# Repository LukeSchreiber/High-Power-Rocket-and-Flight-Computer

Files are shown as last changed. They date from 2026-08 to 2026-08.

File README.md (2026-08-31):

# Model Rocket & ESP32 Flight Computer

A model rocket built from scratch around a custom ESP32-S3 flight computer that logs
barometric altitude, pressure, and temperature to onboard flash at 20 Hz.

The project covers the full build: airframe design in OpenRocket, custom fins, nose cone,
and launch-rail hardware modeled in SOLIDWORKS and 3D printed, firmware written in
Arduino/C++, a homemade igniter and safety-interlock launch controller, and flight testing.

**It flew, the log was recovered, and the measured apogee — 119.1 m (390.7 ft) — matched the
pre-flight OpenRocket prediction to within 0.2%.**

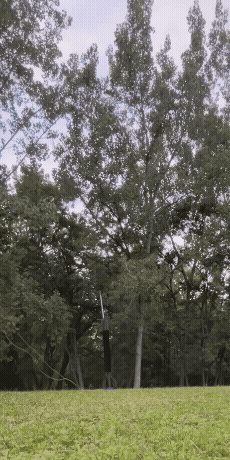
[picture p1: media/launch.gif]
Rocket launching from the field


---

## Flight Computer

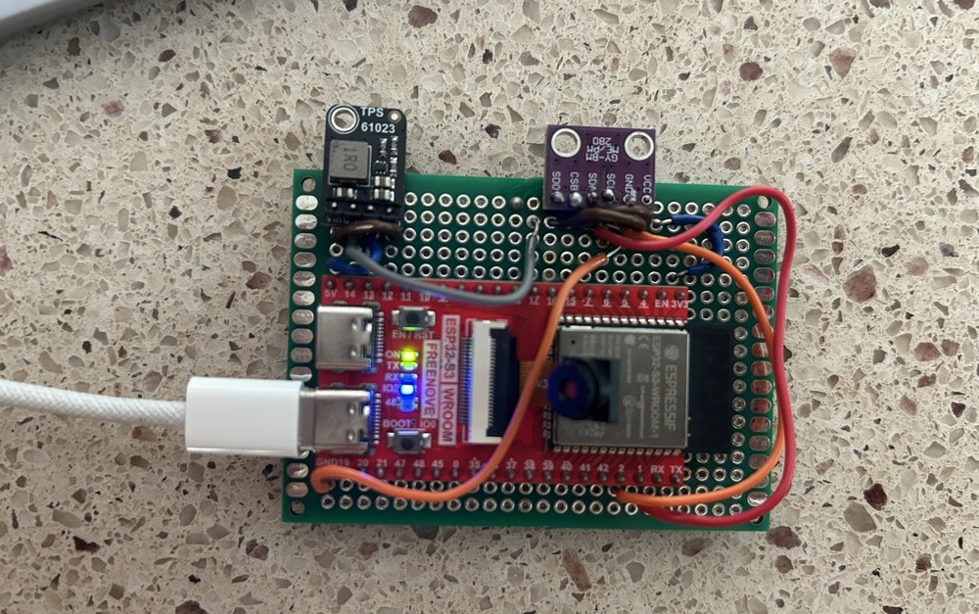
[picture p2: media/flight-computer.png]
ESP32-S3 flight computer on perfboard


| Part | Role |
| --- | --- |
| ESP32-S3 WROOM (Freenove) | Main controller, onboard LittleFS flash storage |
| BME280 (I²C, `0x76`) | Barometric pressure, temperature, derived altitude |
| TPS61023 boost converter | Steps battery voltage up to the board's power rail |
| Perfboard + soldered harness | Flight-ready wiring, no breadboard jumpers |

Wiring is I²C on `SDA = GPIO21`, `SCL = GPIO22`.

### Firmware

[`firmware/Flight_Computer_Program/Flight_Computer_Program.ino`](firmware/Flight_Computer_Program/Flight_Computer_Program.ino)

On boot the firmware averages 10 pressure samples to establish a ground baseline, opens the
next unused `flight_N.csv` on LittleFS, and logs continuously:

- **20 Hz sampling** (50 ms interval), pressure oversampled ×16 for resolution
- **Altitude** derived from the barometric formula against the ground baseline
- **Flushed to flash every second**, so an unexpected power loss costs at most 1 s of data
- **Auto-incrementing flight files** — a new log per power cycle, nothing overwritten

Logged columns: `time_ms, pressure_hPa, temperature_C, altitude_m`

### Serial commands

Connect at **115200 baud** and send a single character:

| Key | Action |
| --- | --- |
| `L` | List stored flight logs and flash usage |
| `D` | Dump all logs over serial for retrieval |
| `W` | Erase all logs |
| `S` | Pause / resume logging |

### Building

Requires the ESP32 board support package plus the `Adafruit_BME280` and `Adafruit_Sensor`
libraries. Open the sketch folder in the Arduino IDE, select an ESP32-S3 board, and upload.

---

## Mechanical Design

Custom components were modeled in SOLIDWORKS and 3D printed. Sources are in
[`cad/solidworks/`](cad/solidworks/), print-ready meshes in [`cad/stl/`](cad/stl/).

| Component | SOLIDWORKS | STL |
| --- | --- | --- |
| Fin can | [RocketFins.SLDPRT](cad/solidworks/RocketFins.SLDPRT) | [RocketFins.STL](cad/stl/RocketFins.STL) |
| Nose cone | [NoseCone.SLDPRT](cad/solidworks/NoseCone.SLDPRT) | [NoseCone.STL](cad/stl/NoseCone.STL) |
| Launch-rail clamp | [RocketClamp.SLDPRT](cad/solidworks/RocketClamp.SLDPRT) | [RocketClamp.STL](cad/stl/RocketClamp.STL) |

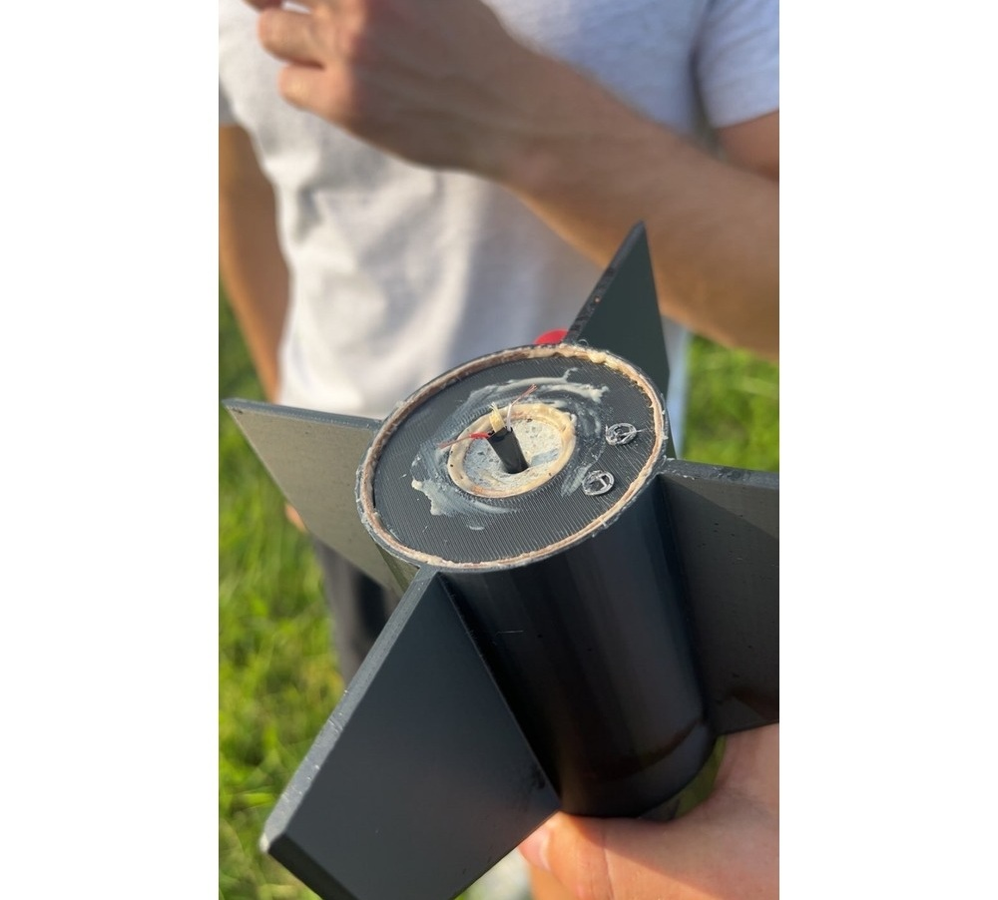
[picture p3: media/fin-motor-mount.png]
Printed fin can and motor mount


The finished airframe — 3D-printed fin can, nose cone, and painted body tube:

<table>
  <tr>
    <td align="center">
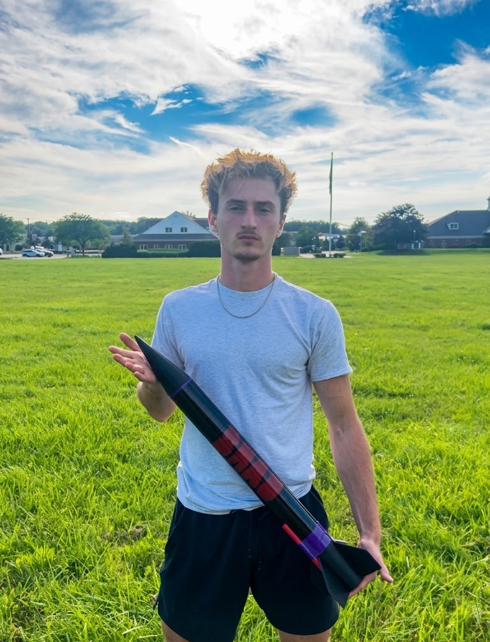
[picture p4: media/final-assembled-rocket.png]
Adriano holding the completed rocket
      <br>
      <sub>Adriano with the completed rocket</sub>
    </td>
    <td align="center">
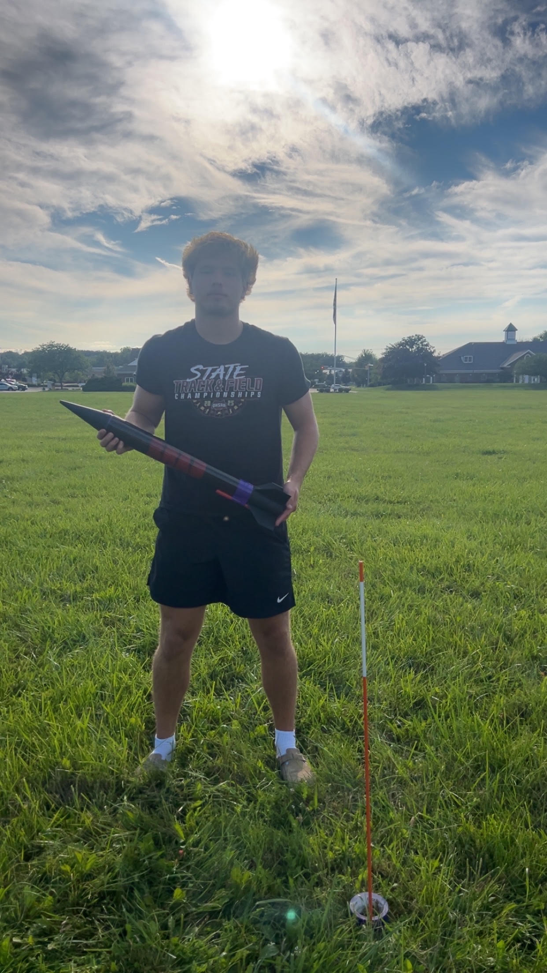
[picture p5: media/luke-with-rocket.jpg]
Luke holding the rocket beside the launch rod
      <br>
      <sub>Luke at the pad before launch</sub>
    </td>
  </tr>
</table>

Recovery is a parachute deployed by the motor's ejection charge.

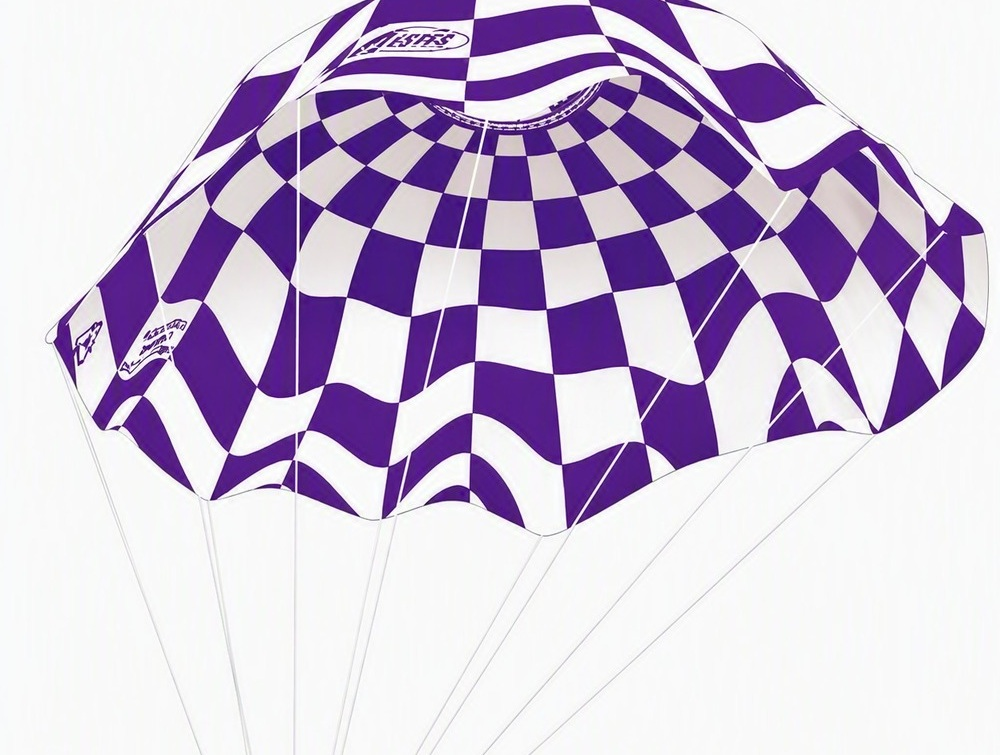
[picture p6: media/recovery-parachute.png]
Recovery parachute


---

## Simulation

[`simulation/RocketProject.ork`](simulation/RocketProject.ork) — OpenRocket model used to size
the airframe and predict the flight profile.

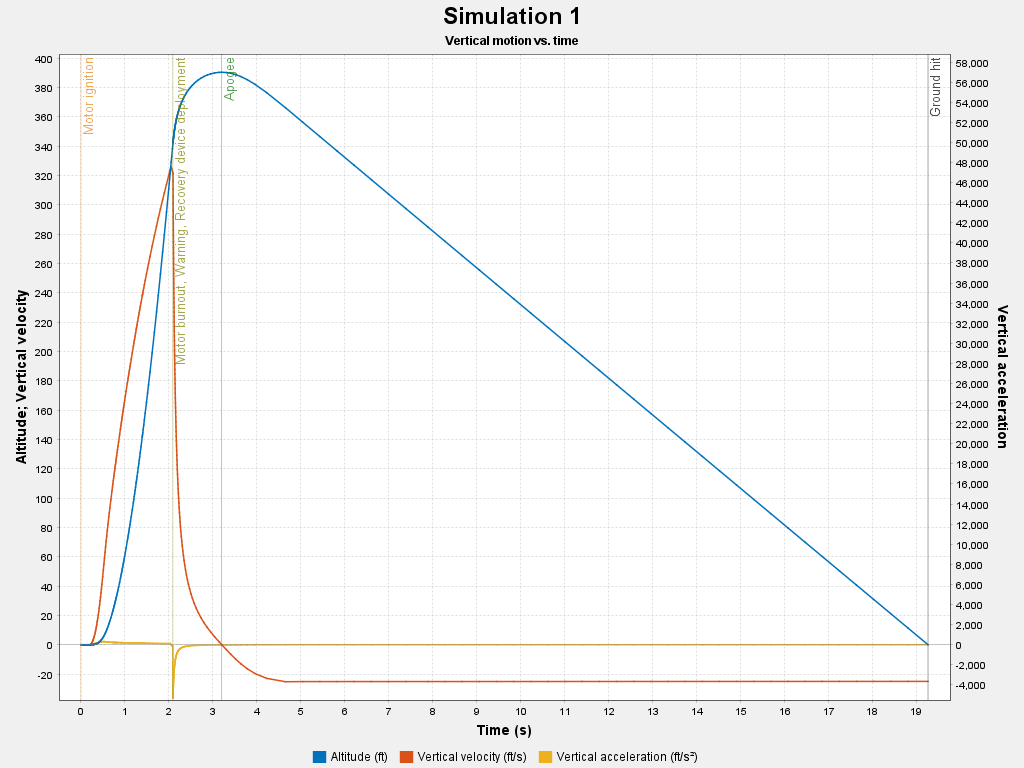
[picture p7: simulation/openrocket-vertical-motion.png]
OpenRocket vertical motion vs. time


| Predicted | Value |
| --- | --- |
| Apogee | 390 ft |
| Time to apogee | 3.2 s |
| Total flight time | 19.3 s |
| Peak velocity | 327 ft/s |
| Peak acceleration | 317 ft/s² |

[`simulation/synthetic_flight_log.xlsx`](simulation/synthetic_flight_log.xlsx) is a phase-labeled
dataset generated from this simulation — not measured telemetry, and marked
`Data_Source = SYNTHETIC_SIMULATION` in the file itself. The real flight log is
[`data/flight_data.csv`](data/flight_data.csv) below.

---

## Measured Flight Data

[`data/flight_data.csv`](data/flight_data.csv) — **401 samples recovered from the flight
computer's flash after the launch.** Twenty seconds of pressure, temperature, and derived
altitude at a steady 20 Hz, exactly as the firmware wrote them.

<picture>
  <source media="(prefers-color-scheme: dark)" srcset="data/flight-profile-dark.svg">
  Measured altitude vs. time: launch, apogee at 119.1 m after 3.2 s, parachute descent, touchdown at 19.2 s
</picture>

| Measurement | Value |
| --- | --- |
| Apogee | **119.1 m (390.7 ft)** at t = 3.20 s |
| Peak climb rate | 94 m/s (307 ft/s) at t ≈ 2.0 s |
| Descent rate under parachute | 7.6 m/s (24.8 ft/s) |
| Touchdown | t = 19.2 s |
| Pressure swing | 1008.79 → 994.57 hPa |
| Temperature | 24.80 °C on the pad → 24.32 °C at apogee |
| Sensor noise on the ground | ±0.2 m |

### Measured vs. predicted

The OpenRocket model was built before the flight. Comparing it against what the rocket
actually did is the real result here:

| | Predicted | Measured | Difference |
| --- | --- | --- | --- |
| Apogee | 390 ft | 390.7 ft | +0.2% |
| Time to apogee | 3.2 s | 3.20 s | — |
| Total flight time | 19.3 s | 19.2 s | −0.5% |
| Peak velocity | 327 ft/s | 307 ft/s | −6% |

Apogee and timing matched the simulation to within a fraction of a percent. The velocity gap
is expected: the flight computer carries no accelerometer, so climb rate is finite-differenced
from barometric altitude, which lags during the ~2 s burn and smooths the true peak.

The ±0.2 m spread in the pre-launch and post-landing samples is the practical altitude
resolution of the BME280 at this configuration — small enough that a 119 m apogee is resolved
to better than 0.2%.

---

## Launch System

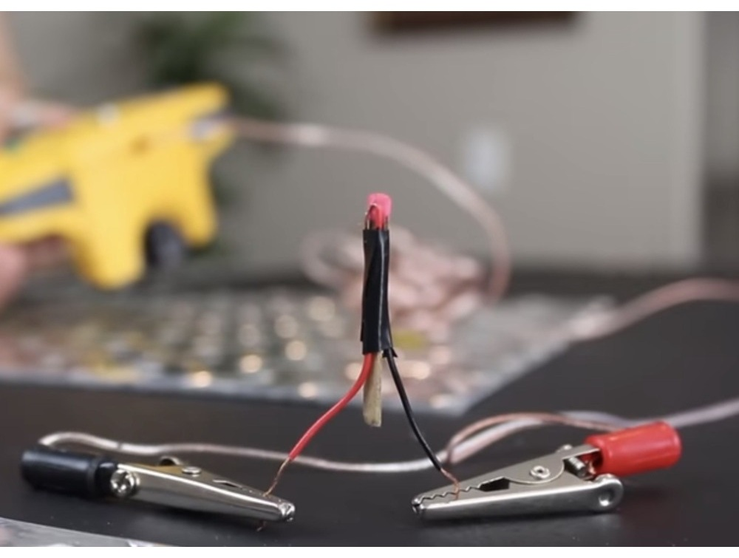
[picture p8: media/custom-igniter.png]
Hand-built nichrome igniter

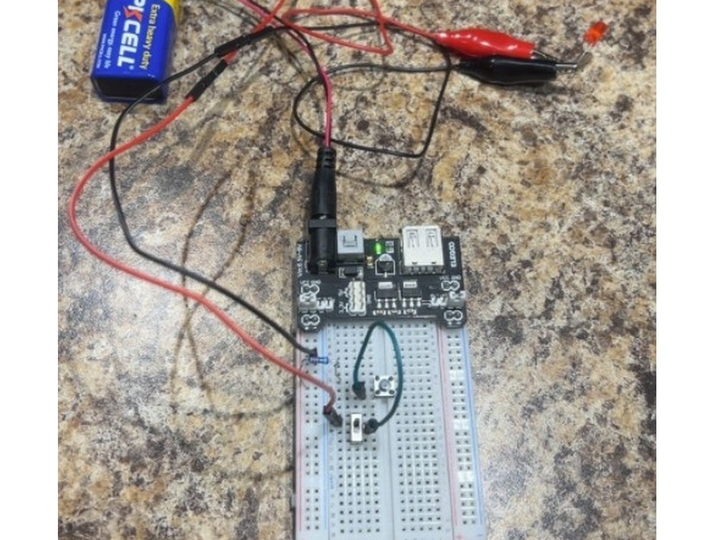
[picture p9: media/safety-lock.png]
Launch controller with safety interlock


A hand-built nichrome igniter fired from a 9 V controller with a **two-stage safety
interlock** — an arming switch in series with a momentary launch button, so the igniter
cannot be energized by a single accidental press.

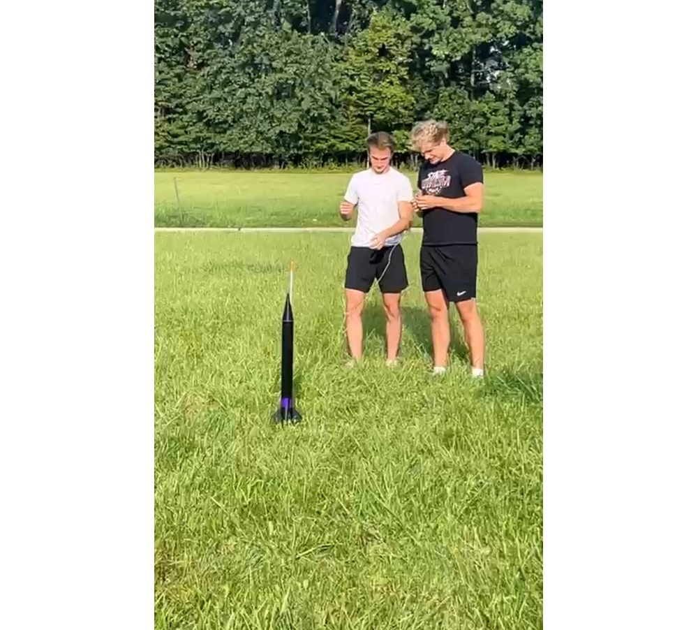
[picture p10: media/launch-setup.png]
Rocket on the pad before launch


---

## Documentation

- [Project report](docs/rocket-flight-computer-report.pdf) — written write-up of the design and build
- [Photo report](docs/rocket-flight-computer-photo-report.pdf) — illustrated build documentation

---

## Repository Structure

```text
.
├── firmware/
│   └── Flight_Computer_Program/     Arduino sketch (ESP32-S3 + BME280 logger)
├── cad/
│   ├── solidworks/                  Editable SOLIDWORKS parts
│   └── stl/                         Print-ready meshes
├── simulation/                      OpenRocket model, predicted profile, synthetic dataset
├── data/                            Measured flight log (CSV) + rendered profile
├── docs/                            Project reports (PDF)
└── media/                           Launch footage and build photos
```

---

## Skills

Embedded C++ · ESP32 · I²C sensor integration · onboard data logging · flight-data analysis ·
simulation validation · SOLIDWORKS · 3D printing · OpenRocket · circuit prototyping and
soldering · flight testing

---

## Status

**Complete and flight-validated.** The airframe, avionics, and launch system were built,
flown, and recovered, and the onboard log was pulled from flash after the flight — the
measured apogee matched the pre-flight simulation to within 0.2%.

---

## Authors

Built as a two-person team project by **Adriano Zagar** and **Luke Schreiber**.

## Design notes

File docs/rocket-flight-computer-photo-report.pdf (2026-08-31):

# Rocket & Flight Computer

LUKE SCHREIBER & TEAM | EMBEDDED C++ / ESP32-S3 / SOLIDWORKS / OPENROCKET

FLIGHT COMPUTER ESP32-S3, hand-soldered perfboard, SD logging

SENSING | BME280 barometric altitude
POWER | TPS61023 boost converter
STRUCTURES | 3D-printed fins, nose cone, motor mount
RECOVERY | Parachute, validated canopy geometry
IGNITION | Custom igniter, key-locked interlock

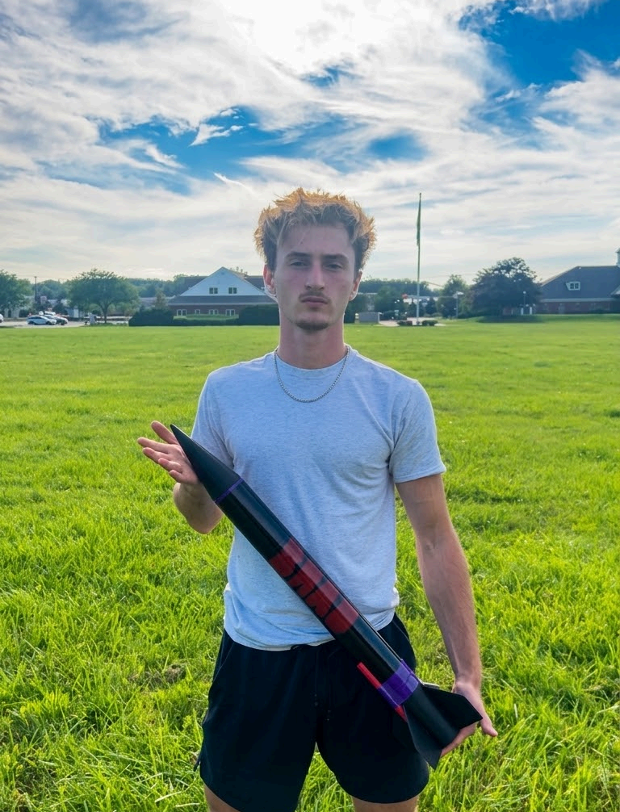
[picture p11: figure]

Final assembled rocket

B U I L D P R O C E S S

01
DESIGN
SOLIDWORKS

02
SIMULATE
OpenRocket

03
FABRICATE
3D print & assemble

04
AVIONICS
Solder & code

05
INTEGRATE
Bench test

06
FLY
Field launches

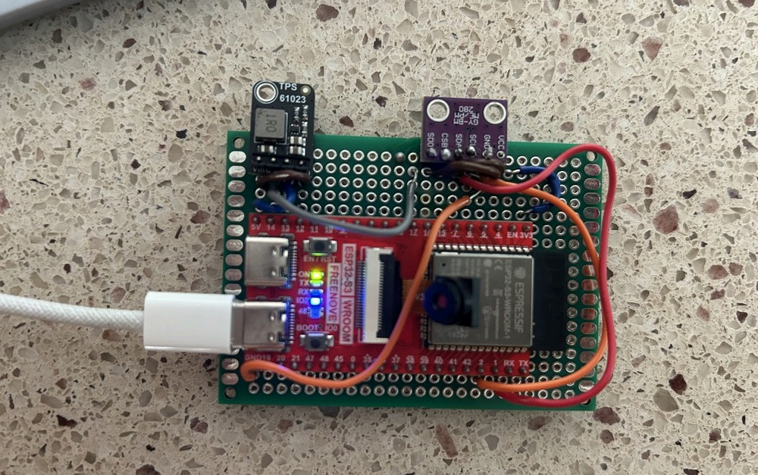
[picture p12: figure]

Flight Computer
ESP32-S3 + BME280

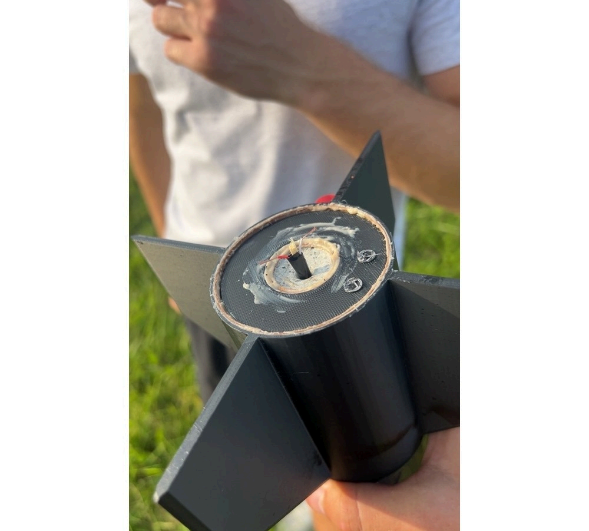
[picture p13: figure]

Fin & Motor Mount
3D printed

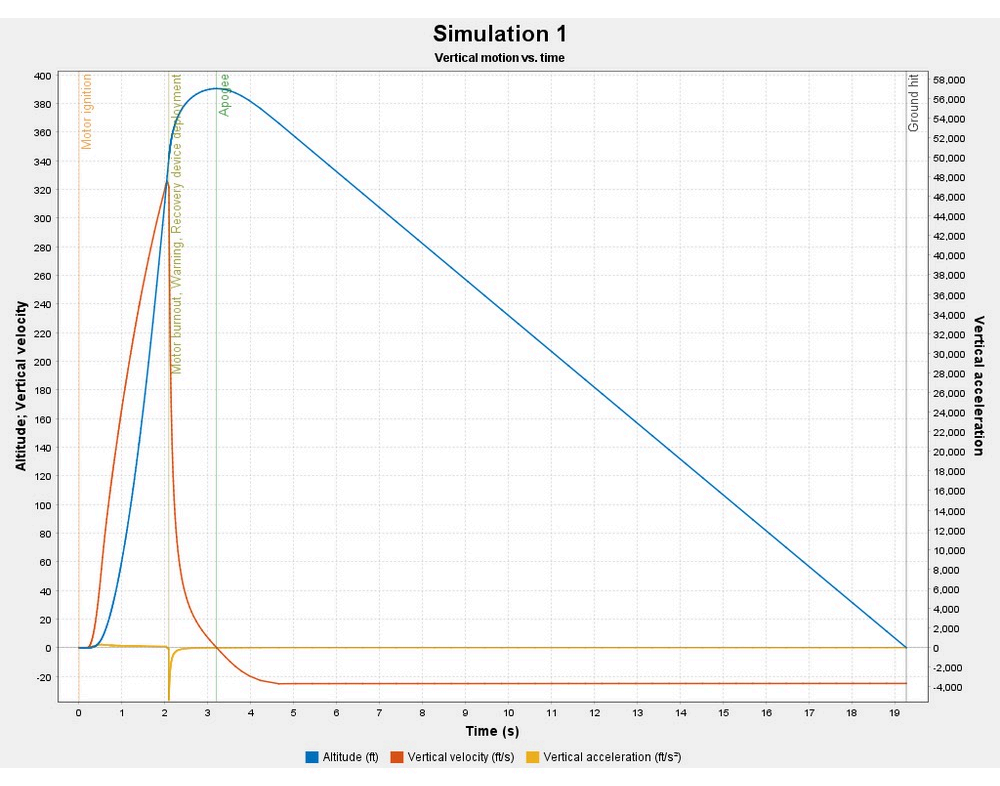
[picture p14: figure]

Flight Simulation
OpenRocket

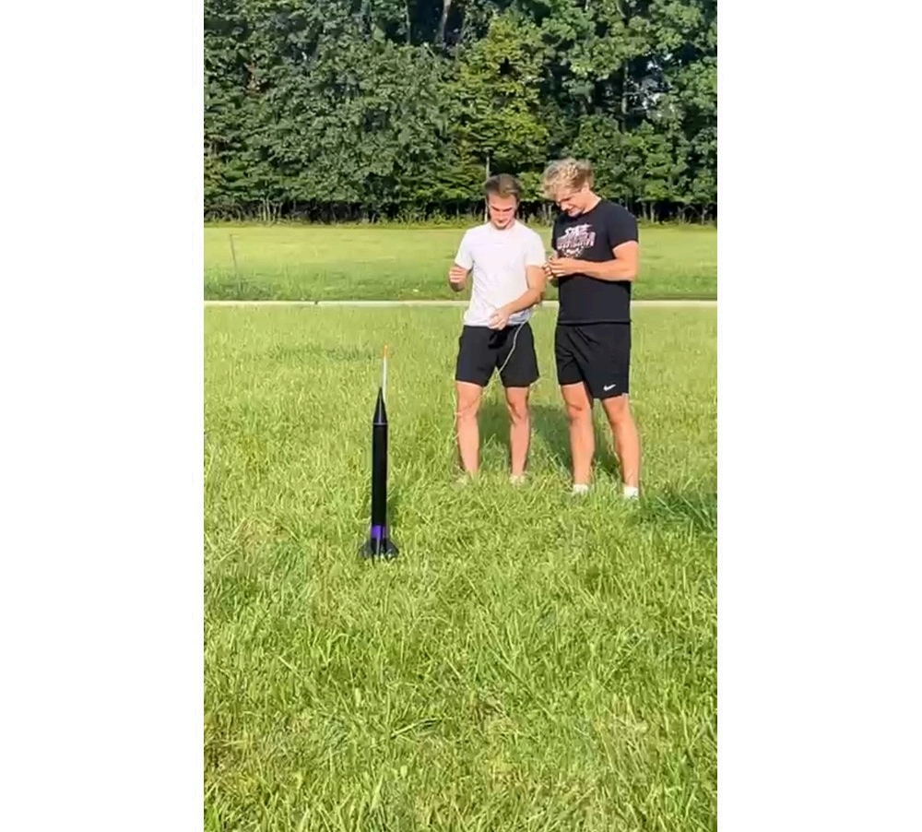
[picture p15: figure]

Launch Setup
Field test

E N G I N E E R I N G H I G H L I G H T S

Igniter built from scratch
No off-the-shelf igniter

Key-locked interlock
Blocks accidental ignition

Validated recovery
Canopy sized for safe descent

Full integration
One flight-ready stack

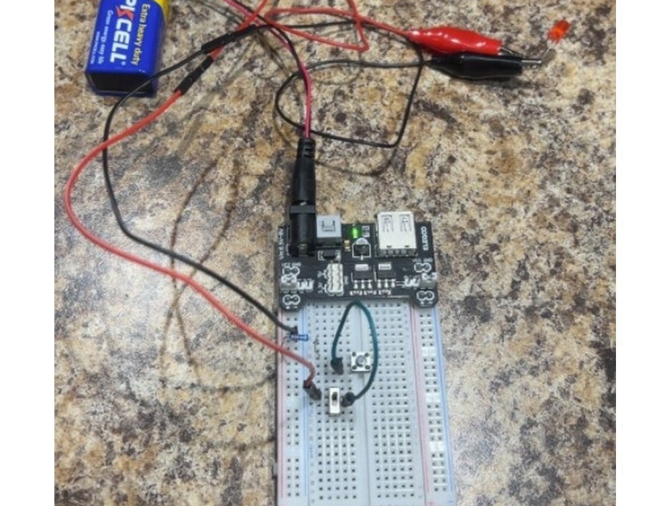
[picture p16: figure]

Safety Lock
Keyed interlock prototype

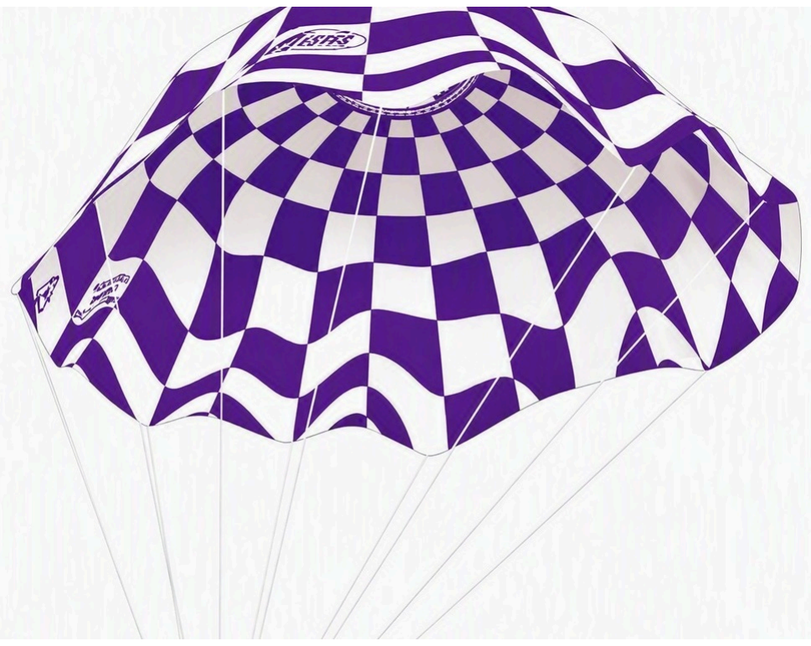
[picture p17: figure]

Recovery Parachute
Canopy layout

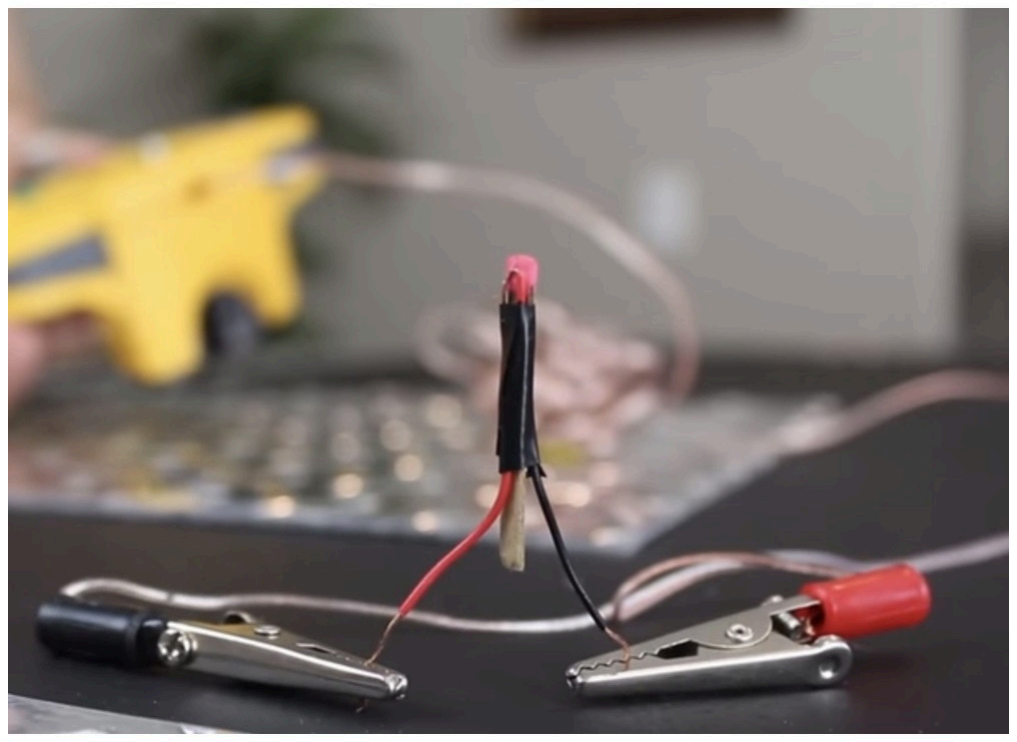
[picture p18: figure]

Custom Igniter
Bench test
LUKE SCHREIBER & TEAM | EMBEDDED SYSTEMS / AEROSTRUCTURES / SYSTEMS INTEGRATION

High-power rocket built with custom avionics, 3D-printed aerostructures, parachute recovery, key-locked ignition.

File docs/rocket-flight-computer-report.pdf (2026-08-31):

# TEAM-DEVELOPED ROCKET AND FLIGHT COMPUTER

Adriano Zagar & Team
Tech Stack: Embedded C++, ESP32-S3, SOLIDWORKS, OpenRocket

OBJECTIVE:Engineered and launched a custom high-power rocket with a self-built ESP32-S3 flight computer, 3D-printed aerostructures, and a custom ignition and safety-lock system.

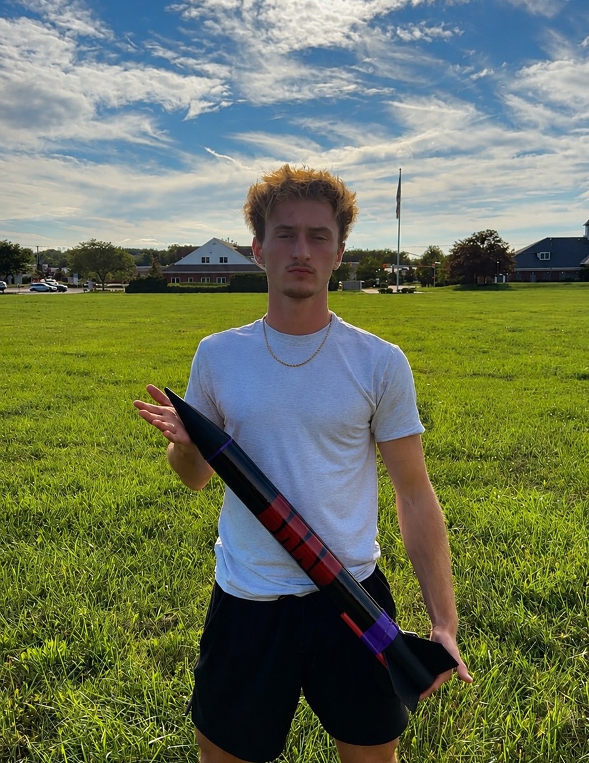
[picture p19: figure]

Final Assembled Rocket

## DEVELOPMENT WORKFLOW

- 1. Flight Computer: Engineered and coded a custom ESP32-S3 flight computer with real-time SD data logging.
- 2. Aerodynamics: Modeled and validated flight stability using OpenRocket simulations.
- 3. Sensor Integration: Integrated a BME280 pressure sensor and TPS61023 boost converter for altitude tracking and stable power delivery.
- 4. 3D-Printed Parts: Designed and fabricated custom fins and nose cone in SOLIDWORKS.
- 5. Ignition & Recovery: Engineered a custom ignition circuit and parachute recovery system from the ground up.
- 6. Flight Testing: Ran iterative test launches to validate flight computer and recovery performance.

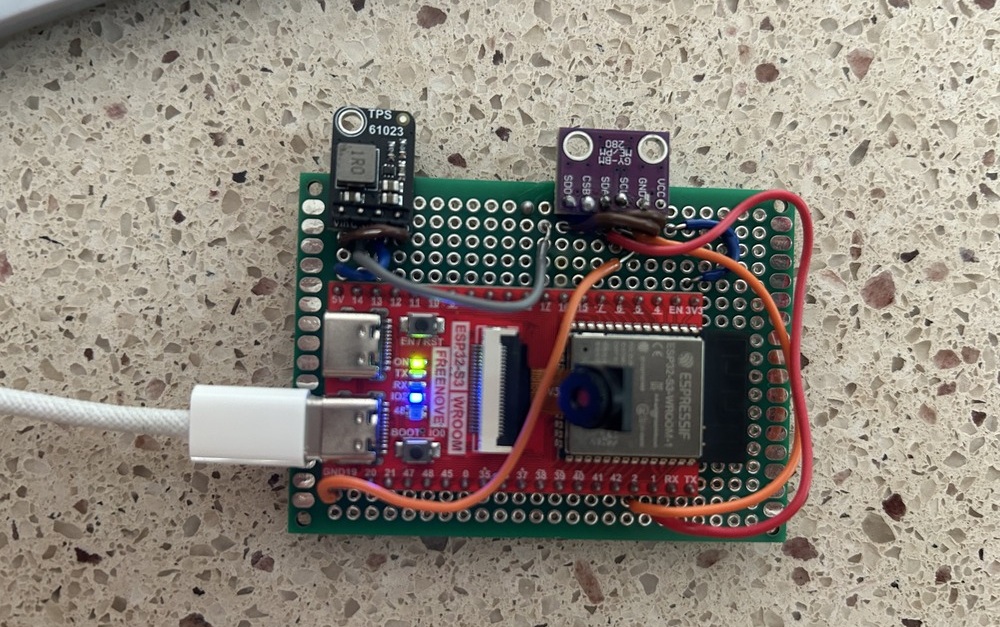
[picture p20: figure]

ESP32-S3 Flight
Computer

3D-Printed Fin & Motor
Mount
OpenRocket Flight Simulation | Rocket Setup

## ENGINEERING CHALLENGES & SOLUTIONS

- Custom Ignition System: Built and tested our own motor igniter circuit rather than using a pre-made one.
- Launch Safety Interlock: Engineered a key-locked launch interlock, adding a dedicated safety stage to prevent accidental ignition.
- Recovery System: Designed and validated parachute deployment and canopy geometry for a safe, controlled descent.
- Full Integration: Unified custom firmware, sensors, and recovery hardware into one fully integrated, flight-ready system.

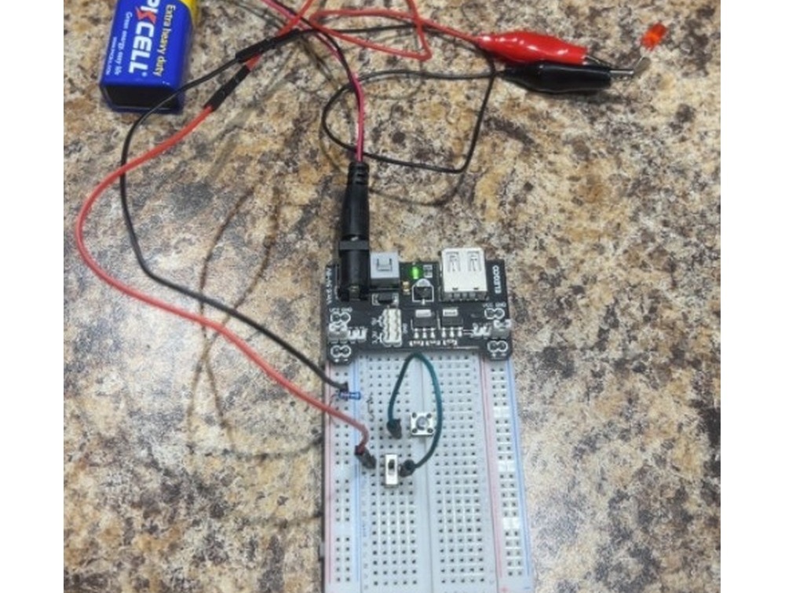
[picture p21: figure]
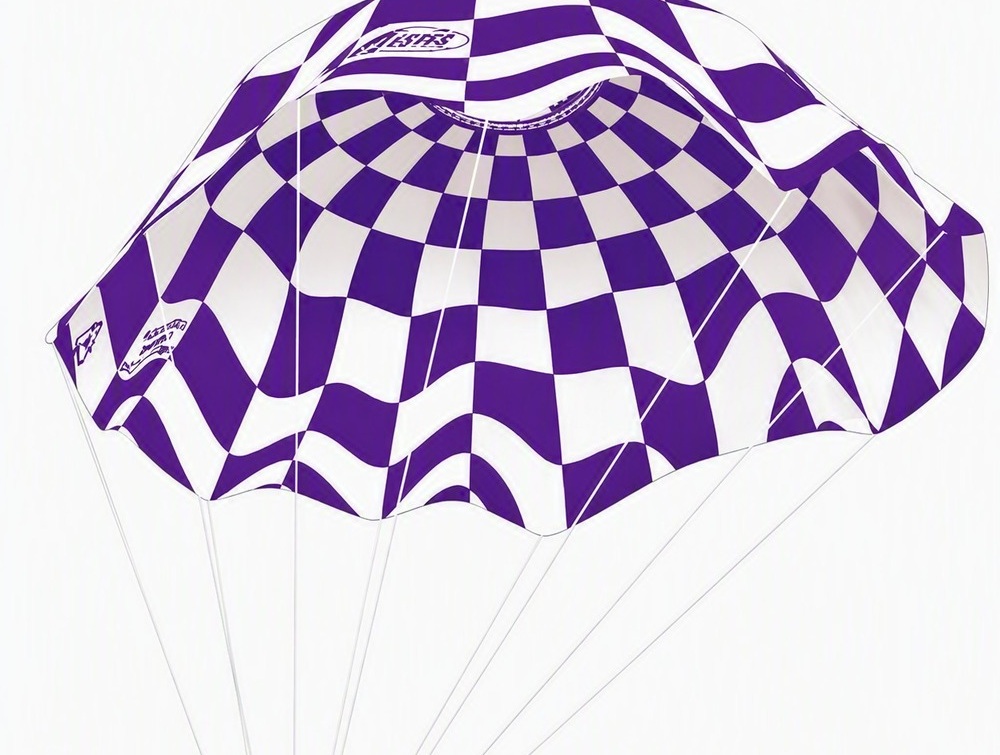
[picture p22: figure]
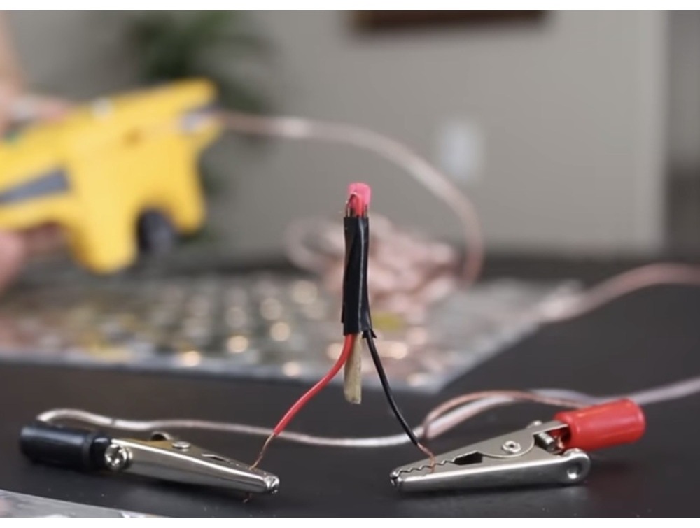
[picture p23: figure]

Safety Lock Prototype | Recovery Parachute | Custom-Built Igniter

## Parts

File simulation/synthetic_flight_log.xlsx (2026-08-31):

Synthetic Rocket Flight Log
Generated from the OpenRocket reference simulation. This is synthetic demonstration data, not an actual launch record.
Target Apogee | Time to Apogee | Total Flight Time | Peak Velocity | Peak Acceleration | Source
390 ft | 3.2 s | 19.3 s | 327 ft/s | 317 ft/s^2 | Synthetic simulation
Time_s | Altitude_ft | Pressure_hPa | Temperature_C | Vertical_Velocity_ft_s | Vertical_Acceleration_ft_s2 | Flight_Phase | Data_Source
0.0 | 0.18 | 1013.24 | 22.40 | 0.00 | 86.00 | Ignition | SYNTHETIC_SIMULATION
0.1 | 0.90 | 1013.28 | 22.41 | 8.63 | 86.72 | Ignition | SYNTHETIC_SIMULATION
0.2 | 2.32 | 1013.27 | 22.43 | 17.38 | 88.58 | Powered Ascent | SYNTHETIC_SIMULATION
0.3 | 4.39 | 1013.21 | 22.43 | 26.38 | 91.58 | Powered Ascent | SYNTHETIC_SIMULATION
0.4 | 7.17 | 1013.09 | 22.44 | 35.74 | 95.72 | Powered Ascent | SYNTHETIC_SIMULATION
0.5 | 10.86 | 1012.92 | 22.44 | 45.56 | 101.00 | Powered Ascent | SYNTHETIC_SIMULATION
0.6 | 15.67 | 1012.69 | 22.44 | 55.97 | 107.42 | Powered Ascent | SYNTHETIC_SIMULATION
0.7 | 21.78 | 1012.40 | 22.43 | 67.08 | 114.98 | Powered Ascent | SYNTHETIC_SIMULATION
0.8 | 29.26 | 1012.08 | 22.42 | 79.01 | 123.68 | Powered Ascent | SYNTHETIC_SIMULATION
0.9 | 38.09 | 1011.74 | 22.40 | 91.86 | 133.52 | Powered Ascent | SYNTHETIC_SIMULATION
1.0 | 48.20 | 1011.38 | 22.38 | 105.75 | 144.50 | Powered Ascent | SYNTHETIC_SIMULATION
1.1 | 59.59 | 1011.00 | 22.35 | 120.80 | 156.62 | Powered Ascent | SYNTHETIC_SIMULATION
1.2 | 72.33 | 1010.59 | 22.32 | 137.11 | 169.88 | Powered Ascent | SYNTHETIC_SIMULATION
1.3 | 86.64 | 1010.12 | 22.28 | 154.81 | 184.28 | Powered Ascent | SYNTHETIC_SIMULATION
1.4 | 102.83 | 1009.58 | 22.23 | 174.01 | 199.82 | Powered Ascent | SYNTHETIC_SIMULATION
1.5 | 121.18 | 1008.94 | 22.18 | 194.81 | 216.50 | Powered Ascent | SYNTHETIC_SIMULATION
1.6 | 141.93 | 1008.18 | 22.13 | 217.34 | 234.32 | Powered Ascent | SYNTHETIC_SIMULATION
1.7 | 165.20 | 1007.30 | 22.07 | 241.71 | 253.28 | Powered Ascent | SYNTHETIC_SIMULATION
1.8 | 191.02 | 1006.31 | 22.00 | 268.04 | 273.38 | Powered Ascent | SYNTHETIC_SIMULATION
1.9 | 219.45 | 1005.21 | 21.93 | 296.43 | 294.62 | Powered Ascent | SYNTHETIC_SIMULATION
2.0 | 250.58 | 1004.03 | 21.85 | 327.00 | 317.00 | Powered Ascent | SYNTHETIC_SIMULATION
2.1 | 280.57 | 1002.90 | 21.78 | 278.28 | -467.64 | Coast to Apogee | SYNTHETIC_SIMULATION
2.2 | 305.79 | 1001.99 | 21.73 | 233.47 | -428.61 | Coast to Apogee | SYNTHETIC_SIMULATION
2.3 | 326.78 | 1001.25 | 21.68 | 192.56 | -389.58 | Coast to Apogee | SYNTHETIC_SIMULATION
2.4 | 344.07 | 1000.68 | 21.64 | 155.56 | -350.56 | Coast to Apogee | SYNTHETIC_SIMULATION
2.5 | 358.06 | 1000.23 | 21.61 | 122.45 | -311.53 | Coast to Apogee | SYNTHETIC_SIMULATION
2.6 | 369.07 | 999.89 | 21.59 | 93.25 | -272.50 | Coast to Apogee | SYNTHETIC_SIMULATION
2.7 | 377.33 | 999.62 | 21.58 | 67.95 | -233.47 | Coast to Apogee | SYNTHETIC_SIMULATION
2.8 | 383.09 | 999.42 | 21.58 | 46.56 | -194.44 | Coast to Apogee | SYNTHETIC_SIMULATION
2.9 | 386.68 | 999.27 | 21.58 | 29.06 | -155.42 | Coast to Apogee | SYNTHETIC_SIMULATION
3.0 | 388.58 | 999.15 | 21.59 | 15.47 | -116.39 | Coast to Apogee | SYNTHETIC_SIMULATION
3.1 | 389.30 | 999.07 | 21.60 | 5.78 | -77.36 | Coast to Apogee | SYNTHETIC_SIMULATION
3.2 | 389.40 | 999.01 | 21.61 | 0.00 | -38.33 | Apogee | SYNTHETIC_SIMULATION
3.3 | 387.06 | 999.05 | 21.63 | -24.22 | 0.00 | Parachute Descent | SYNTHETIC_SIMULATION
3.4 | 384.94 | 999.12 | 21.65 | -24.22 | 0.00 | Parachute Descent | SYNTHETIC_SIMULATION
3.5 | 382.89 | 999.21 | 21.67 | -24.22 | 0.00 | Parachute Descent | SYNTHETIC_SIMULATION
3.6 | 380.75 | 999.33 | 21.69 | -24.22 | 0.00 | Parachute Descent | SYNTHETIC_SIMULATION
3.7 | 378.40 | 999.48 | 21.70 | -24.22 | 0.00 | Parachute Descent | SYNTHETIC_SIMULATION
3.8 | 375.82 | 999.63 | 21.72 | -24.22 | 0.00 | Parachute Descent | SYNTHETIC_SIMULATION
3.9 | 373.12 | 999.77 | 21.73 | -24.22 | 0.00 | Parachute Descent | SYNTHETIC_SIMULATION
4.0 | 370.44 | 999.88 | 21.74 | -24.22 | 0.00 | Parachute Descent | SYNTHETIC_SIMULATION
4.1 | 367.93 | 999.96 | 21.75 | -24.22 | 0.00 | Parachute Descent | SYNTHETIC_SIMULATION
4.2 | 365.63 | 1000.00 | 21.75 | -24.22 | 0.00 | Parachute Descent | SYNTHETIC_SIMULATION
4.3 | 363.47 | 1000.02 | 21.76 | -24.22 | 0.00 | Parachute Descent | SYNTHETIC_SIMULATION
4.4 | 361.31 | 1000.04 | 21.75 | -24.22 | 0.00 | Parachute Descent | SYNTHETIC_SIMULATION
4.5 | 358.99 | 1000.08 | 21.75 | -24.22 | 0.00 | Parachute Descent | SYNTHETIC_SIMULATION
4.6 | 356.44 | 1000.15 | 21.74 | -24.22 | 0.00 | Parachute Descent | SYNTHETIC_SIMULATION
4.7 | 353.70 | 1000.26 | 21.74 | -24.22 | 0.00 | Parachute Descent | SYNTHETIC_SIMULATION
4.8 | 350.91 | 1000.40 | 21.73 | -24.22 | 0.00 | Parachute Descent | SYNTHETIC_SIMULATION
4.9 | 348.24 | 1000.55 | 21.72 | -24.22 | 0.00 | Parachute Descent | SYNTHETIC_SIMULATION
5.0 | 345.80 | 1000.70 | 21.71 | -24.22 | 0.00 | Parachute Descent | SYNTHETIC_SIMULATION
5.1 | 343.59 | 1000.83 | 21.70 | -24.22 | 0.00 | Parachute Descent | SYNTHETIC_SIMULATION
5.2 | 341.50 | 1000.93 | 21.69 | -24.22 | 0.00 | Parachute Descent | SYNTHETIC_SIMULATION
5.3 | 339.37 | 1001.00 | 21.68 | -24.22 | 0.00 | Parachute Descent | SYNTHETIC_SIMULATION
5.4 | 337.06 | 1001.05 | 21.67 | -24.22 | 0.00 | Parachute Descent | SYNTHETIC_SIMULATION
5.5 | 334.53 | 1001.09 | 21.67 | -24.22 | 0.00 | Parachute Descent | SYNTHETIC_SIMULATION
5.6 | 331.86 | 1001.13 | 21.67 | -24.22 | 0.00 | Parachute Descent | SYNTHETIC_SIMULATION
5.7 | 329.20 | 1001.17 | 21.67 | -24.22 | 0.00 | Parachute Descent | SYNTHETIC_SIMULATION
5.8 | 326.69 | 1001.23 | 21.67 | -24.22 | 0.00 | Parachute Descent | SYNTHETIC_SIMULATION
5.9 | 324.39 | 1001.31 | 21.68 | -24.22 | 0.00 | Parachute Descent | SYNTHETIC_SIMULATION
6.0 | 322.27 | 1001.42 | 21.69 | -24.22 | 0.00 | Parachute Descent | SYNTHETIC_SIMULATION
6.1 | 320.17 | 1001.55 | 21.70 | -24.22 | 0.00 | Parachute Descent | SYNTHETIC_SIMULATION
6.2 | 317.93 | 1001.69 | 21.71 | -24.22 | 0.00 | Parachute Descent | SYNTHETIC_SIMULATION
6.3 | 315.45 | 1001.83 | 21.73 | -24.22 | 0.00 | Parachute Descent | SYNTHETIC_SIMULATION
6.4 | 312.76 | 1001.96 | 21.75 | -24.22 | 0.00 | Parachute Descent | SYNTHETIC_SIMULATION
6.5 | 309.97 | 1002.07 | 21.77 | -24.22 | 0.00 | Parachute Descent | SYNTHETIC_SIMULATION
6.6 | 307.24 | 1002.15 | 21.79 | -24.22 | 0.00 | Parachute Descent | SYNTHETIC_SIMULATION
6.7 | 304.72 | 1002.19 | 21.81 | -24.22 | 0.00 | Parachute Descent | SYNTHETIC_SIMULATION
6.8 | 302.42 | 1002.21 | 21.83 | -24.22 | 0.00 | Parachute Descent | SYNTHETIC_SIMULATION
6.9 | 300.27 | 1002.23 | 21.85 | -24.22 | 0.00 | Parachute Descent | SYNTHETIC_SIMULATION
7.0 | 298.11 | 1002.27 | 21.86 | -24.22 | 0.00 | Parachute Descent | SYNTHETIC_SIMULATION
7.1 | 295.80 | 1002.35 | 21.88 | -24.22 | 0.00 | Parachute Descent | SYNTHETIC_SIMULATION
7.2 | 293.27 | 1002.46 | 21.89 | -24.22 | 0.00 | Parachute Descent | SYNTHETIC_SIMULATION
7.3 | 290.59 | 1002.60 | 21.90 | -24.22 | 0.00 | Parachute Descent | SYNTHETIC_SIMULATION
7.4 | 287.90 | 1002.76 | 21.91 | -24.22 | 0.00 | Parachute Descent | SYNTHETIC_SIMULATION
7.5 | 285.34 | 1002.91 | 21.91 | -24.22 | 0.00 | Parachute Descent | SYNTHETIC_SIMULATION
7.6 | 283.02 | 1003.04 | 21.92 | -24.22 | 0.00 | Parachute Descent | SYNTHETIC_SIMULATION
7.7 | 280.90 | 1003.13 | 21.91 | -24.22 | 0.00 | Parachute Descent | SYNTHETIC_SIMULATION
7.8 | 278.85 | 1003.19 | 21.91 | -24.22 | 0.00 | Parachute Descent | SYNTHETIC_SIMULATION
7.9 | 276.70 | 1003.22 | 21.90 | -24.22 | 0.00 | Parachute Descent | SYNTHETIC_SIMULATION
8.0 | 274.33 | 1003.25 | 21.90 | -24.22 | 0.00 | Parachute Descent | SYNTHETIC_SIMULATION
8.1 | 271.72 | 1003.29 | 21.89 | -24.22 | 0.00 | Parachute Descent | SYNTHETIC_SIMULATION
8.2 | 268.98 | 1003.34 | 21.88 | -24.22 | 0.00 | Parachute Descent | SYNTHETIC_SIMULATION
8.3 | 266.26 | 1003.42 | 21.87 | -24.22 | 0.00 | Parachute Descent | SYNTHETIC_SIMULATION
8.4 | 263.70 | 1003.52 | 21.86 | -24.22 | 0.00 | Parachute Descent | SYNTHETIC_SIMULATION
8.5 | 261.36 | 1003.65 | 21.85 | -24.22 | 0.00 | Parachute Descent | SYNTHETIC_SIMULATION
8.6 | 259.18 | 1003.78 | 21.84 | -24.22 | 0.00 | Parachute Descent | SYNTHETIC_SIMULATION
8.7 | 257.01 | 1003.92 | 21.83 | -24.22 | 0.00 | Parachute Descent | SYNTHETIC_SIMULATION
8.8 | 254.69 | 1004.05 | 21.83 | -24.22 | 0.00 | Parachute Descent | SYNTHETIC_SIMULATION
8.9 | 252.17 | 1004.17 | 21.83 | -24.22 | 0.00 | Parachute Descent | SYNTHETIC_SIMULATION
9.0 | 249.46 | 1004.26 | 21.83 | -24.22 | 0.00 | Parachute Descent | SYNTHETIC_SIMULATION
9.1 | 246.70 | 1004.33 | 21.83 | -24.22 | 0.00 | Parachute Descent | SYNTHETIC_SIMULATION
9.2 | 244.07 | 1004.37 | 21.84 | -24.22 | 0.00 | Parachute Descent | SYNTHETIC_SIMULATION
9.3 | 241.66 | 1004.40 | 21.85 | -24.22 | 0.00 | Parachute Descent | SYNTHETIC_SIMULATION
9.4 | 239.48 | 1004.43 | 21.86 | -24.22 | 0.00 | Parachute Descent | SYNTHETIC_SIMULATION
9.5 | 237.43 | 1004.47 | 21.87 | -24.22 | 0.00 | Parachute Descent | SYNTHETIC_SIMULATION
9.6 | 235.32 | 1004.55 | 21.89 | -24.22 | 0.00 | Parachute Descent | SYNTHETIC_SIMULATION
9.7 | 233.03 | 1004.66 | 21.91 | -24.22 | 0.00 | Parachute Descent | SYNTHETIC_SIMULATION
9.8 | 230.51 | 1004.81 | 21.93 | -24.22 | 0.00 | Parachute Descent | SYNTHETIC_SIMULATION
9.9 | 227.83 | 1004.96 | 21.95 | -24.22 | 0.00 | Parachute Descent | SYNTHETIC_SIMULATION
10.0 | 225.14 | 1005.12 | 21.97 | -24.22 | 0.00 | Parachute Descent | SYNTHETIC_SIMULATION
10.1 | 222.59 | 1005.24 | 21.99 | -24.22 | 0.00 | Parachute Descent | SYNTHETIC_SIMULATION
10.2 | 220.25 | 1005.33 | 22.00 | -24.22 | 0.00 | Parachute Descent | SYNTHETIC_SIMULATION
10.3 | 218.08 | 1005.38 | 22.02 | -24.22 | 0.00 | Parachute Descent | SYNTHETIC_SIMULATION
10.4 | 215.94 | 1005.41 | 22.04 | -24.22 | 0.00 | Parachute Descent | SYNTHETIC_SIMULATION
10.5 | 213.67 | 1005.43 | 22.05 | -24.22 | 0.00 | Parachute Descent | SYNTHETIC_SIMULATION
10.6 | 211.18 | 1005.47 | 22.06 | -24.22 | 0.00 | Parachute Descent | SYNTHETIC_SIMULATION
10.7 | 208.48 | 1005.53 | 22.07 | -24.22 | 0.00 | Parachute Descent | SYNTHETIC_SIMULATION
10.8 | 205.68 | 1005.62 | 22.07 | -24.22 | 0.00 | Parachute Descent | SYNTHETIC_SIMULATION
10.9 | 202.96 | 1005.74 | 22.07 | -24.22 | 0.00 | Parachute Descent | SYNTHETIC_SIMULATION
11.0 | 200.45 | 1005.88 | 22.07 | -24.22 | 0.00 | Parachute Descent | SYNTHETIC_SIMULATION
11.1 | 198.18 | 1006.02 | 22.07 | -24.22 | 0.00 | Parachute Descent | SYNTHETIC_SIMULATION
11.2 | 196.07 | 1006.16 | 22.06 | -24.22 | 0.00 | Parachute Descent | SYNTHETIC_SIMULATION
11.3 | 193.95 | 1006.28 | 22.06 | -24.22 | 0.00 | Parachute Descent | SYNTHETIC_SIMULATION
11.4 | 191.69 | 1006.37 | 22.05 | -24.22 | 0.00 | Parachute Descent | SYNTHETIC_SIMULATION
11.5 | 189.21 | 1006.45 | 22.04 | -24.22 | 0.00 | Parachute Descent | SYNTHETIC_SIMULATION
11.6 | 186.56 | 1006.50 | 22.03 | -24.22 | 0.00 | Parachute Descent | SYNTHETIC_SIMULATION
11.7 | 183.88 | 1006.54 | 22.02 | -24.22 | 0.00 | Parachute Descent | SYNTHETIC_SIMULATION
11.8 | 181.32 | 1006.57 | 22.01 | -24.22 | 0.00 | Parachute Descent | SYNTHETIC_SIMULATION
11.9 | 178.98 | 1006.61 | 22.00 | -24.22 | 0.00 | Parachute Descent | SYNTHETIC_SIMULATION
12.0 | 176.83 | 1006.67 | 21.99 | -24.22 | 0.00 | Parachute Descent | SYNTHETIC_SIMULATION
12.1 | 174.75 | 1006.76 | 21.99 | -24.22 | 0.00 | Parachute Descent | SYNTHETIC_SIMULATION
12.2 | 172.57 | 1006.88 | 21.98 | -24.22 | 0.00 | Parachute Descent | SYNTHETIC_SIMULATION
12.3 | 170.16 | 1007.02 | 21.98 | -24.22 | 0.00 | Parachute Descent | SYNTHETIC_SIMULATION
12.4 | 167.52 | 1007.18 | 21.99 | -24.22 | 0.00 | Parachute Descent | SYNTHETIC_SIMULATION
12.5 | 164.75 | 1007.33 | 22.00 | -24.22 | 0.00 | Parachute Descent | SYNTHETIC_SIMULATION
12.6 | 161.99 | 1007.45 | 22.00 | -24.22 | 0.00 | Parachute Descent | SYNTHETIC_SIMULATION
12.7 | 159.41 | 1007.54 | 22.02 | -24.22 | 0.00 | Parachute Descent | SYNTHETIC_SIMULATION
12.8 | 157.06 | 1007.59 | 22.03 | -24.22 | 0.00 | Parachute Descent | SYNTHETIC_SIMULATION
12.9 | 154.88 | 1007.61 | 22.05 | -24.22 | 0.00 | Parachute Descent | SYNTHETIC_SIMULATION
13.0 | 152.73 | 1007.63 | 22.06 | -24.22 | 0.00 | Parachute Descent | SYNTHETIC_SIMULATION
13.1 | 150.45 | 1007.66 | 22.08 | -24.22 | 0.00 | Parachute Descent | SYNTHETIC_SIMULATION
13.2 | 147.97 | 1007.73 | 22.10 | -24.22 | 0.00 | Parachute Descent | SYNTHETIC_SIMULATION
13.3 | 145.31 | 1007.83 | 22.12 | -24.22 | 0.00 | Parachute Descent | SYNTHETIC_SIMULATION
13.4 | 142.59 | 1007.96 | 22.14 | -24.22 | 0.00 | Parachute Descent | SYNTHETIC_SIMULATION
13.5 | 139.99 | 1008.10 | 22.16 | -24.22 | 0.00 | Parachute Descent | SYNTHETIC_SIMULATION
13.6 | 137.60 | 1008.25 | 22.18 | -24.22 | 0.00 | Parachute Descent | SYNTHETIC_SIMULATION
13.7 | 135.44 | 1008.38 | 22.19 | -24.22 | 0.00 | Parachute Descent | SYNTHETIC_SIMULATION
13.8 | 133.39 | 1008.49 | 22.21 | -24.22 | 0.00 | Parachute Descent | SYNTHETIC_SIMULATION
13.9 | 131.28 | 1008.57 | 22.22 | -24.22 | 0.00 | Parachute Descent | SYNTHETIC_SIMULATION
14.0 | 128.98 | 1008.63 | 22.22 | -24.22 | 0.00 | Parachute Descent | SYNTHETIC_SIMULATION
14.1 | 126.44 | 1008.67 | 22.23 | -24.22 | 0.00 | Parachute Descent | SYNTHETIC_SIMULATION
14.2 | 123.73 | 1008.71 | 22.23 | -24.22 | 0.00 | Parachute Descent | SYNTHETIC_SIMULATION
14.3 | 120.99 | 1008.75 | 22.23 | -24.22 | 0.00 | Parachute Descent | SYNTHETIC_SIMULATION
14.4 | 118.39 | 1008.81 | 22.23 | -24.22 | 0.00 | Parachute Descent | SYNTHETIC_SIMULATION
14.5 | 116.01 | 1008.89 | 22.22 | -24.22 | 0.00 | Parachute Descent | SYNTHETIC_SIMULATION
14.6 | 113.80 | 1008.99 | 22.22 | -24.22 | 0.00 | Parachute Descent | SYNTHETIC_SIMULATION
14.7 | 111.64 | 1009.12 | 22.21 | -24.22 | 0.00 | Parachute Descent | SYNTHETIC_SIMULATION
14.8 | 109.37 | 1009.26 | 22.20 | -24.22 | 0.00 | Parachute Descent | SYNTHETIC_SIMULATION
14.9 | 106.89 | 1009.41 | 22.19 | -24.22 | 0.00 | Parachute Descent | SYNTHETIC_SIMULATION
15.0 | 104.21 | 1009.55 | 22.18 | -24.22 | 0.00 | Parachute Descent | SYNTHETIC_SIMULATION
15.1 | 101.45 | 1009.66 | 22.17 | -24.22 | 0.00 | Parachute Descent | SYNTHETIC_SIMULATION
15.2 | 98.76 | 1009.74 | 22.16 | -24.22 | 0.00 | Parachute Descent | SYNTHETIC_SIMULATION
15.3 | 96.28 | 1009.79 | 22.15 | -24.22 | 0.00 | Parachute Descent | SYNTHETIC_SIMULATION
15.4 | 94.04 | 1009.81 | 22.15 | -24.22 | 0.00 | Parachute Descent | SYNTHETIC_SIMULATION
15.5 | 91.97 | 1009.83 | 22.14 | -24.22 | 0.00 | Parachute Descent | SYNTHETIC_SIMULATION
15.6 | 89.89 | 1009.86 | 22.14 | -24.22 | 0.00 | Parachute Descent | SYNTHETIC_SIMULATION
15.7 | 87.65 | 1009.93 | 22.15 | -24.22 | 0.00 | Parachute Descent | SYNTHETIC_SIMULATION
15.8 | 85.19 | 1010.03 | 22.15 | -24.22 | 0.00 | Parachute Descent | SYNTHETIC_SIMULATION
15.9 | 82.54 | 1010.17 | 22.16 | -24.22 | 0.00 | Parachute Descent | SYNTHETIC_SIMULATION
16.0 | 79.84 | 1010.32 | 22.17 | -24.22 | 0.00 | Parachute Descent | SYNTHETIC_SIMULATION
16.1 | 77.25 | 1010.47 | 22.19 | -24.22 | 0.00 | Parachute Descent | SYNTHETIC_SIMULATION
16.2 | 74.87 | 1010.61 | 22.20 | -24.22 | 0.00 | Parachute Descent | SYNTHETIC_SIMULATION
16.3 | 72.67 | 1010.71 | 22.22 | -24.22 | 0.00 | Parachute Descent | SYNTHETIC_SIMULATION
16.4 | 70.55 | 1010.78 | 22.24 | -24.22 | 0.00 | Parachute Descent | SYNTHETIC_SIMULATION
16.5 | 68.33 | 1010.83 | 22.26 | -24.22 | 0.00 | Parachute Descent | SYNTHETIC_SIMULATION
16.6 | 65.91 | 1010.86 | 22.28 | -24.22 | 0.00 | Parachute Descent | SYNTHETIC_SIMULATION
16.7 | 63.25 | 1010.90 | 22.30 | -24.22 | 0.00 | Parachute Descent | SYNTHETIC_SIMULATION
16.8 | 60.46 | 1010.95 | 22.32 | -24.22 | 0.00 | Parachute Descent | SYNTHETIC_SIMULATION
16.9 | 57.70 | 1011.02 | 22.34 | -24.22 | 0.00 | Parachute Descent | SYNTHETIC_SIMULATION
17.0 | 55.13 | 1011.12 | 22.35 | -24.22 | 0.00 | Parachute Descent | SYNTHETIC_SIMULATION
17.1 | 52.79 | 1011.24 | 22.37 | -24.22 | 0.00 | Parachute Descent | SYNTHETIC_SIMULATION
17.2 | 50.64 | 1011.37 | 22.38 | -24.22 | 0.00 | Parachute Descent | SYNTHETIC_SIMULATION
17.3 | 48.54 | 1011.51 | 22.38 | -24.22 | 0.00 | Parachute Descent | SYNTHETIC_SIMULATION
17.4 | 46.31 | 1011.64 | 22.39 | -24.22 | 0.00 | Parachute Descent | SYNTHETIC_SIMULATION
17.5 | 43.87 | 1011.76 | 22.39 | -24.22 | 0.00 | Parachute Descent | SYNTHETIC_SIMULATION
17.6 | 41.25 | 1011.86 | 22.39 | -24.22 | 0.00 | Parachute Descent | SYNTHETIC_SIMULATION
17.7 | 38.56 | 1011.93 | 22.39 | -24.22 | 0.00 | Parachute Descent | SYNTHETIC_SIMULATION
17.8 | 35.96 | 1011.97 | 22.38 | -24.22 | 0.00 | Parachute Descent | SYNTHETIC_SIMULATION
17.9 | 33.57 | 1012.00 | 22.38 | -24.22 | 0.00 | Parachute Descent | SYNTHETIC_SIMULATION
18.0 | 31.39 | 1012.02 | 22.37 | -24.22 | 0.00 | Parachute Descent | SYNTHETIC_SIMULATION
18.1 | 29.31 | 1012.07 | 22.36 | -24.22 | 0.00 | Parachute Descent | SYNTHETIC_SIMULATION
18.2 | 27.18 | 1012.14 | 22.34 | -24.22 | 0.00 | Parachute Descent | SYNTHETIC_SIMULATION
18.3 | 24.85 | 1012.25 | 22.33 | -24.22 | 0.00 | Parachute Descent | SYNTHETIC_SIMULATION
18.4 | 22.27 | 1012.39 | 22.32 | -24.22 | 0.00 | Parachute Descent | SYNTHETIC_SIMULATION
18.5 | 19.52 | 1012.55 | 22.32 | -24.22 | 0.00 | Parachute Descent | SYNTHETIC_SIMULATION
18.6 | 16.75 | 1012.71 | 22.31 | -24.22 | 0.00 | Parachute Descent | SYNTHETIC_SIMULATION
18.7 | 14.12 | 1012.84 | 22.31 | -24.22 | 0.00 | Parachute Descent | SYNTHETIC_SIMULATION
18.8 | 11.71 | 1012.94 | 22.30 | -24.22 | 0.00 | Parachute Descent | SYNTHETIC_SIMULATION
18.9 | 9.49 | 1013.00 | 22.30 | -24.22 | 0.00 | Parachute Descent | SYNTHETIC_SIMULATION
19.0 | 7.34 | 1013.04 | 22.31 | -24.22 | 0.00 | Parachute Descent | SYNTHETIC_SIMULATION
19.1 | 5.10 | 1013.06 | 22.31 | -24.22 | 0.00 | Parachute Descent | SYNTHETIC_SIMULATION
19.2 | 2.67 | 1013.09 | 22.32 | -24.22 | 0.00 | Parachute Descent | SYNTHETIC_SIMULATION
19.3 | 0.00 | 1013.15 | 22.33 | 0.00 | 0.00 | Landed | SYNTHETIC_SIMULATION

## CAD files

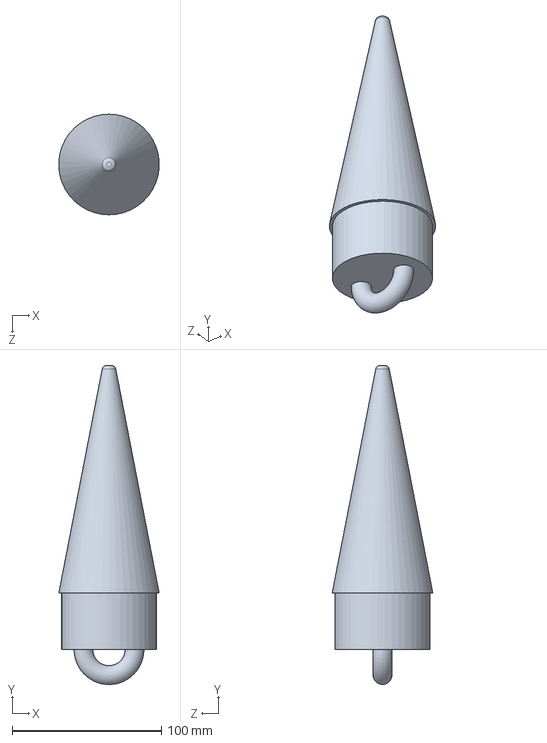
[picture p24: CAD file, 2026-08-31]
cad/solidworks/NoseCone.SLDPRT
67.3 x 213.9 x 67.5 mm

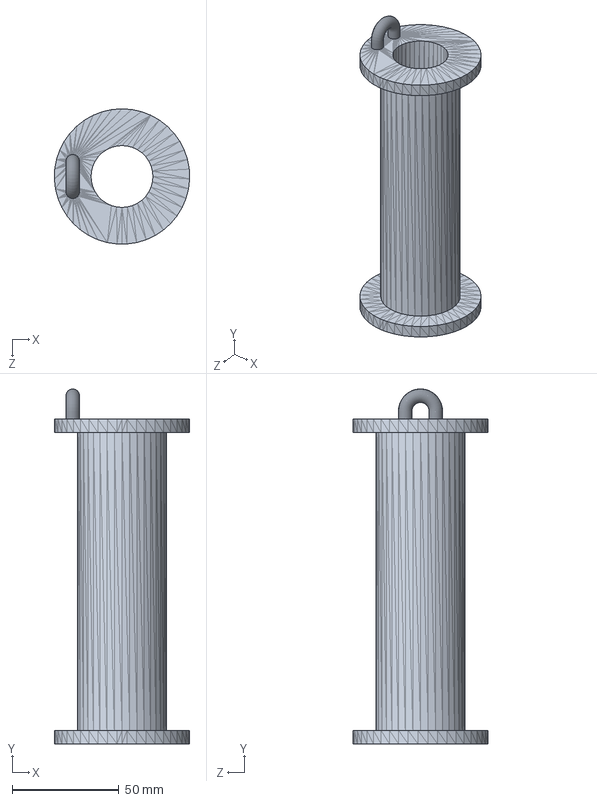
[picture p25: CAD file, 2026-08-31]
cad/solidworks/RocketClamp.SLDPRT
63.5 x 166.5 x 63.5 mm

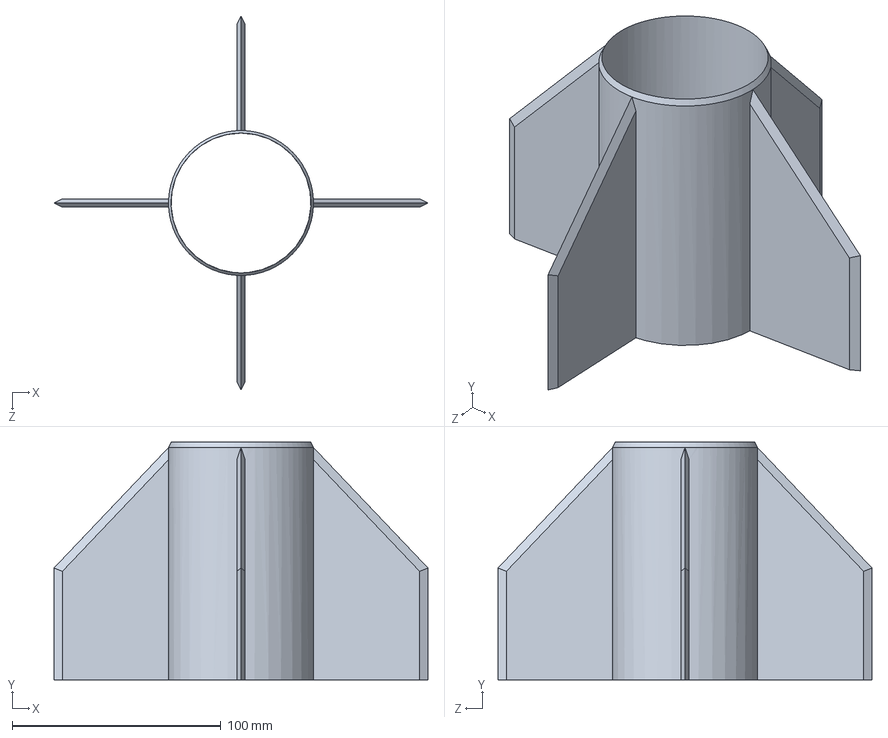
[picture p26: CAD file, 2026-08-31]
cad/solidworks/RocketFins.SLDPRT
179.3 x 113.9 x 179.3 mm

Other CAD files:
cad/stl/NoseCone.STL
cad/stl/RocketClamp.STL
cad/stl/RocketFins.STL

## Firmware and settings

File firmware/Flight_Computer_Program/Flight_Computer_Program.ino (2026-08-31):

#include <Wire.h>
#include <Adafruit_Sensor.h>
#include <Adafruit_BME280.h>
#include <FS.h>
#include <LittleFS.h>

#define SDA_PIN 21
#define SCL_PIN 22
#define BME280_ADDRESS 0x76

#define LOG_INTERVAL_MS 50      // ~20Hz
#define FLUSH_INTERVAL_MS 1000  // flush to flash every 1s
#define BASELINE_SAMPLES 10

Adafruit_BME280 bme;
File logFile;
char logPath[32];

float groundPressure = 0;
unsigned long startTime = 0;
unsigned long lastLog = 0;
unsigned long lastFlush = 0;
bool logging = false;

// ---------- flight file naming ----------
int nextFlightNumber() {
  int maxNum = 0;
  File root = LittleFS.open("/");
  File f = root.openNextFile();
  while (f) {
    int n;
    if (sscanf(f.name(), "flight_%d.csv", &n) == 1) {
      if (n > maxNum) maxNum = n;
    }
    f = root.openNextFile();
  }
  return maxNum + 1;
}

// ---------- serial commands ----------
void listFiles() {
  Serial.println("--- FILES ---");
  File root = LittleFS.open("/");
  File f = root.openNextFile();
  while (f) {
    Serial.printf("%s  (%u bytes)\n", f.name(), f.size());
    f = root.openNextFile();
  }
  Serial.printf("Used: %u / %u bytes\n", LittleFS.usedBytes(), LittleFS.totalBytes());
  Serial.println("--- END ---");
}

void dumpAll() {
  File root = LittleFS.open("/");
  File f = root.openNextFile();
  while (f) {
    Serial.printf("===== BEGIN %s =====\n", f.name());
    while (f.available()) Serial.write(f.read());
    Serial.printf("\n===== END %s =====\n", f.name());
    f = root.openNextFile();
  }
}

void wipeAll() {
  if (logging) { logFile.close(); logging = false; }
  File root = LittleFS.open("/");
  File f = root.openNextFile();
  while (f) {
    String path = String("/") + f.name();
    f = root.openNextFile();
    LittleFS.remove(path);
  }
  Serial.println("All logs erased. Reset board to start a new flight.");
}

void handleSerial() {
  if (!Serial.available()) return;
  char c = Serial.read();
  if (c == 'd' || c == 'D') { dumpAll(); }
  else if (c == 'l' || c == 'L') { listFiles(); }
  else if (c == 'w' || c == 'W') { wipeAll(); }
  else if (c == 's' || c == 'S') {
    logging = !logging;
    Serial.println(logging ? "Logging RESUMED" : "Logging PAUSED");
  }
}

void setup() {
  Serial.begin(115200);
  delay(1000);

  Wire.begin(SDA_PIN, SCL_PIN);
  if (!bme.begin(BME280_ADDRESS, &Wire)) {
    Serial.println("BME280 not found at 0x76. Check wiring.");
    while (1) delay(10);
  }
  Serial.println("BME280 OK");

  // max sampling, IIR filter off for fast response
  bme.setSampling(Adafruit_BME280::MODE_NORMAL,
                  Adafruit_BME280::SAMPLING_X2,   // temperature
                  Adafruit_BME280::SAMPLING_X16,  // pressure
                  Adafruit_BME280::SAMPLING_NONE, // humidity off
                  Adafruit_BME280::FILTER_X4,
                  Adafruit_BME280::STANDBY_MS_0_5);

  if (!LittleFS.begin(true)) {   // true = format if mount fails
    Serial.println("LittleFS mount failed.");
    while (1) delay(10);
  }
  Serial.println("LittleFS mounted");
  listFiles();

  // ground baseline
  Serial.println("Averaging ground baseline, hold still...");
  float sum = 0;
  for (int i = 0; i < BASELINE_SAMPLES; i++) {
    sum += bme.readPressure() / 100.0F;
    delay(100);
  }
  groundPressure = sum / BASELINE_SAMPLES;
  Serial.printf("Ground pressure: %.2f hPa\n", groundPressure);

  snprintf(logPath, sizeof(logPath), "/flight_%d.csv", nextFlightNumber());
  logFile = LittleFS.open(logPath, FILE_WRITE);
  if (!logFile) {
    Serial.println("Failed to open log file!");
    while (1) delay(10);
  }
  logFile.printf("# ground_pressure_hPa,%.2f\n", groundPressure);
  logFile.println("time_ms,pressure_hPa,temperature_C,altitude_m");
  logFile.flush();

  Serial.printf("Logging to %s\n", logPath);
  Serial.println("Commands: L=list  D=dump  W=wipe  S=start/stop");

  startTime = millis();
  lastFlush = millis();
  logging = true;
}

void loop() {
  handleSerial();

  unsigned long now = millis();
  if (logging && now - lastLog >= LOG_INTERVAL_MS) {
    lastLog = now;

    float pressure = bme.readPressure() / 100.0F;
    float temperature = bme.readTemperature();
    float altitude = 44330.0 * (1.0 - pow(pressure / groundPressure, 0.1903));

    logFile.printf("%lu,%.2f,%.2f,%.2f\n", now - startTime, pressure, temperature, altitude);

    if (now - lastFlush >= FLUSH_INTERVAL_MS) {
      logFile.flush();
      lastFlush = now;
    }
  }
}

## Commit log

2026-08-31 Expand README with project details and structure
    Added detailed project overview, key features, tech stack, development process, and engineering challenges for the high-power rocket and flight computer project.
2026-08-31 Update README to remove high-power rocket section
    Removed project title and description for high-power rocket.
2026-08-31 Reorganize repository and rewrite README
    Restructure files into firmware/, cad/, simulation/, data/, docs/, and
    media/ directories. The Arduino sketch now lives in a folder matching its
    name so the Arduino IDE can open it directly.
    - Extract rocket-project-images.zip into media/ so build photos render in
    the README instead of requiring a download
    - Add launch footage as media/launch.gif
    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
    [NoseCone.SLDPRT, NoseCone.STL, RocketClamp.SLDPRT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]
2026-08-31 Add recovered flight log and validate against the simulation
    Add data/flight_data.csv, the 401-sample log pulled from the flight
    computer's flash after the launch: 20 s of pressure, temperature, and
    derived altitude at 20 Hz.
    - Render the measured profile as light/dark SVGs, annotated with burnout,
    apogee, parachute descent, and touchdown
    - Add a measured-vs-predicted comparison: apogee 390.7 ft against a
    predicted 390 ft, and flight time 19.2 s against 19.3 s
    - Note that peak climb rate is finite-differenced from barometric altitude
    rather than measured, since the board carries no accelerometer
    - Move the synthetic workbook to simulation/synthetic_flight_log.xlsx so
    generated data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
    [flight_data.csv, synthetic_flight_log.xlsx]
